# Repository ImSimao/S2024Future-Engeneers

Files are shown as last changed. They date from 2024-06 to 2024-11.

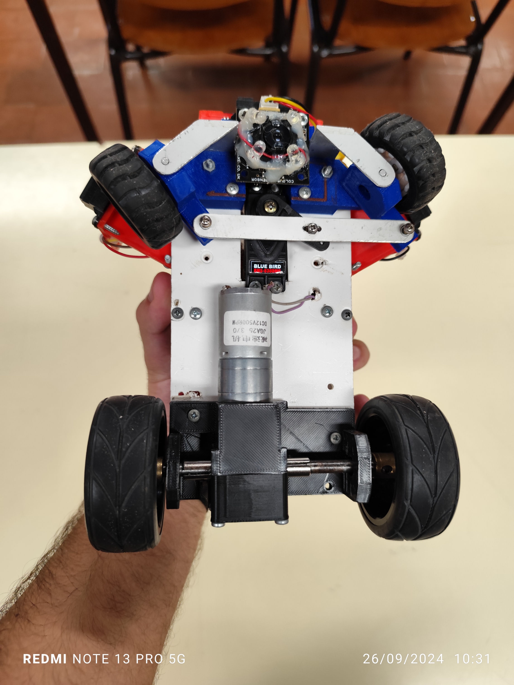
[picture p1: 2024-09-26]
v-photos/Under.jpg

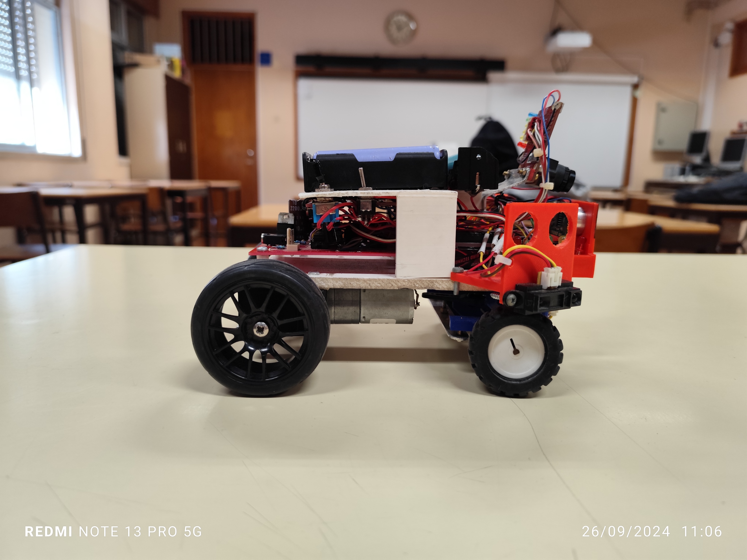
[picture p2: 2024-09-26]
v-photos/Side2.jpg

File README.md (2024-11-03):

# Team and competition

## Presentation of the AGSG Team
We are the AGSG team, we are students and our name is Joana Silva, Simão Freire and Rafael Teodoro, under the guidance of our mentor Tiago Severino. We have the honour to represent Portugal in the World Robot Olympiad competition, in the Future Engineers category.

Official Team

## Competition Challenge
The main challenge in this category is to explore the fundamentals of autonomous driving by building a robot in the shape of a car. This robot must be able to navigate autonomously around a defined track, detecting and dodging obstacles, as well as adapting dynamically to the different conditions imposed during the competition.
Autonomous driving is one of the most significant advances in modern engineering, with applications ranging from personal vehicles to public transport solutions. This challenge not only allows us to demonstrate our skills as a team, but also promotes a space for the exchange of ideas and collaborative learning, contributing to joint evolution in the field of engineering.

## Repository Content
- `other` is for other files which can be used to understand how to prepare the vehicle for the competition. It may include documentation how to connect to a SBC/SBM and upload files there, datasets, hardware specifications, communication protocols descriptions etc. If there is nothing to add to this location, the directory can be removed.
- `schemes` contains one or several schematic diagrams in form of JPEG, PNG or PDF of the electromechanical components illustrating all the elements (electronic components and motors) used in the vehicle and how they connect to each other.
- `src` contains code of control software for all components which were programmed to participate in the competition.
- `t-photos` contains 2 photos of the team (an official one and one funny photo with all team members).
- `v-photos` contains 6 photos of the vehicle (from every side, from top and bottom).
- `video` contains the video.md file with the link to a video where driving demonstration exists.
- `models` is for the files for models used by 3D printers, laser cutting machines and CNC machines to produce the vehicle elements. If there is nothing to add to this location, the directory can be removed.

# Robot Description

## Materials used
The structure of our robot is mostly manufactured using 3D printing or recycled components. For the printed parts, we start with prior planning that includes the shape and dimensions required. We then design the parts using the Tinkercad application and carry out a final visualisation in 3D visualisation software to ensure that the specifications meet our needs before printing. Regarding the parts we reuse, one example is the differential of a toy car, which we adapt to the needs of our robot by giving new life to components that would otherwise be discarded.

Capturar 26 Capturar 25

## Robot Scheme
esquema do robot

## The code: general
We used two software applications to develop our robot. Most of the programming was done in the PICAXE programming editor application, using the PICAXE Basic language. For the camera, we opted for OpenMV, programming in Python.
We have developed three programmes in PICAXE:
      1.	A general programme that controls the robot's movements on the track, reacting when it detects a can, dodges walls, it also reverses or parks.
      2.	A second programme is responsible for reading the blue and orange lines on the track mat, informing the robot in which direction the lap is being taken (clockwise or anti-clockwise) and when to reverse or park.
      3.	A third program that optimises the vehicle's movement, allowing it to move forwards or backwards, saving programming resources and freeing up space in the general programming for other functionalities.
In Python, we programmed the camera to distinguish the colour of green and red obstacles, sending information to the main programming about the direction the robot should go. It also identifies the colour of the car park walls to locate the correct area.

#### The Code: Setup and Compilation
To program, compile and upload the code to the robot we use the picaxe IDE, which is based in basic. When the IDE is running, it asks for the picaxe version, and the cable port. In our robot we use 4 processors, the main processor is a picaxe 28x2, that handles and runs the main code, two processors are slaves, one picaxe 14M2, for the RGB (red, green and blue)  sensor and line counting and the other slave is a picaxe 28x2 for handling the motors. The last processor is integrated in the camera from OpenMV and is programmed in python.
The processors communicate with each other through bits.
The picaxe IDE can be found at https://www.picaxe.com/ it is also needed to install de drivers so it can recognize the cable used for programming, they can also be found at the picaxe website.

#### The Code: Camera
For the camera we use an OpenMV H7 camera and to program it and calibrate it we use the OpenMV IDE. All the libraries required are present in the OpenMV IDE.
In the beginning of the code we initialize the libraries used for the camera The variable screen_division is used to divide the screen in X sections, for example X=3, the screen will be divided and only the bottom 2/3 of the screen will be used to track the obstacles. Then we initialized the variables green_blobs, red_blobs and pink_blobs. The blobs refer to the colour detected by the camera and their position in the screen. Each bracket represents the colour code seen by the camera, there are a few parameters because of the different angles that the camera can see the obstacles.



These thresholds can be obtained from the menu tools/machine vision/Threshold Editor.



Then we adjust the sliders to track just the object that we want to track.



After getting the colour values, we use the blobs position in the screen to send bits to the main processor indicating if the blobs detected are green or red and if they are on the right, left or in the middle.
We also use 1 bit to indicate if it is seeing the parking spot (looking for the pink colour).



Sending the bits to the main processor.



## Mobility Management
Our vehicle is equipped with four wheels, a motor and a differential, which connects the rear wheels. The front wheels are responsible for steering, controlled by a servo that allows the robot to turn left or right as required. The rear wheels connected to the differential was the configuration developed to solve a problem we faced, guaranteeing an even distribution of torque between the half shafts, enabling them to turn in opposite directions and have a different speed range.

Capturar 27

## Energy Management
The robot is powered by four batteries, one of which is a separate power source dedicated specifically to the camera. This approach was implemented to avoid power failures in the camera that would compromise its functionality in distinguishing colours, a challenge we faced during the development of our vehicle.

Capturar 28

## Sensors Management
We chose to use a camera to detect obstacles and the car park, equipping it with a lens that widens the field of view, which solved the difficulties in detecting two consecutive obstacles in a corner. In addition, we incorporated three infrared sensors (Sharp) on the front of the robot: one on each side and one in the centre, capable of measuring the distance to objects by emitting and receiving infrared light. To increase the robot's obstacle detection range, we also added a sonar sensor in the centre of the robot, which measures distances by emitting and receiving sound waves. To identify the colours of the blue and orange lines on the carpet, we used an RGB (red, green and blue) colour sensor, which allows the robot to determine the direction of the race and its position on the laps.

Capturar 31
## Obstacle Management
With regard to obstacle detection, the robot uses the camera with the magnifying lens to identify obstacles, as well as locating the walls of the car park. We have implemented a strategy that allows the robot to bypass obstacles as soon as it detects them, moving to the right if the obstacle is red and to the left if it is green.

# Conclusion
Summarizing, our experience building and programming the robot for the World Robot Olympiad competition not only challenged us to apply theoretical knowledge to a practical project, but also strengthened the spirit of collaboration and innovation within our team. By integrating technologies such as 3D printing, programming in different languages and sensor management, we were able to create a robot capable of navigating autonomously, adapting to different scenarios. We went through several difficulties, some of which are described in this report, and managed to overcome them all, although with a lot of effort, this is a source of great pride.  We are excited to represent Portugal and look forward in applying everything we have learnt when preparing for this competition.

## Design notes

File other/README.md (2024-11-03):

# Other photos taken during the manufactoring process

This board shows photos of the new board we put in the robot when we changed it due to a problem with the previous board and of the soldering of cables that broke and we had to fix. There's also a clear picture of the inside of the robot all together.

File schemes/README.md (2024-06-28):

Electromechanical diagrams
====

The camera schematics can be found at the openmv webiste: https://openmv.io/products/openmv-cam-h7

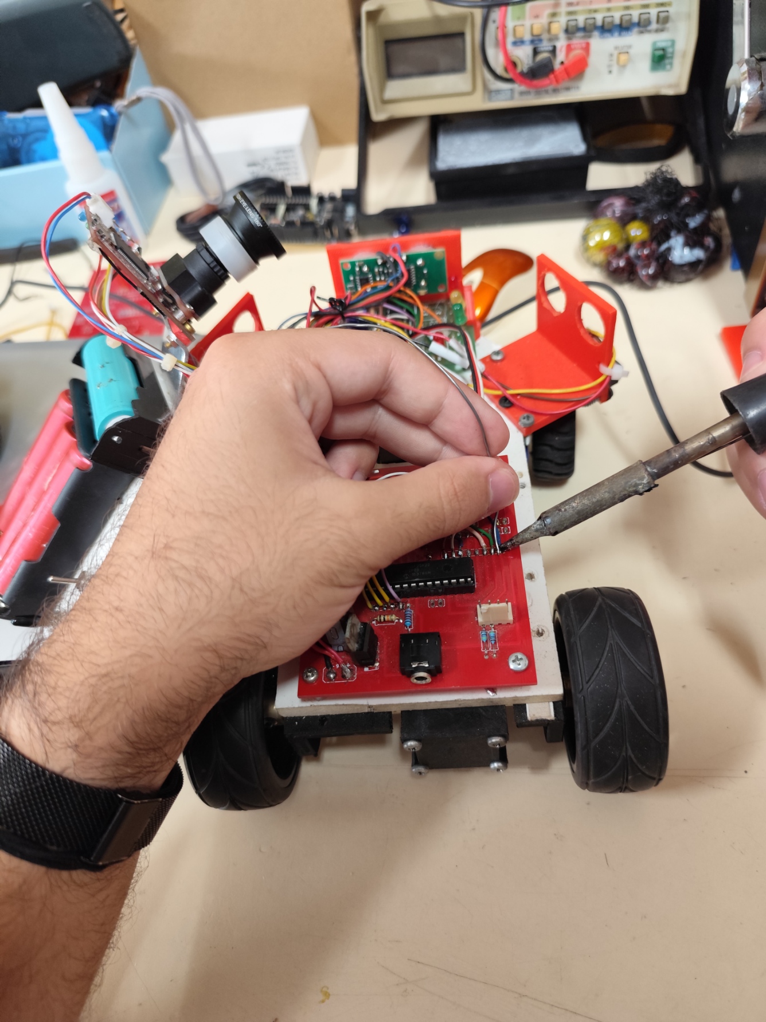
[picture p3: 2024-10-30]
other/broken cable.jpg

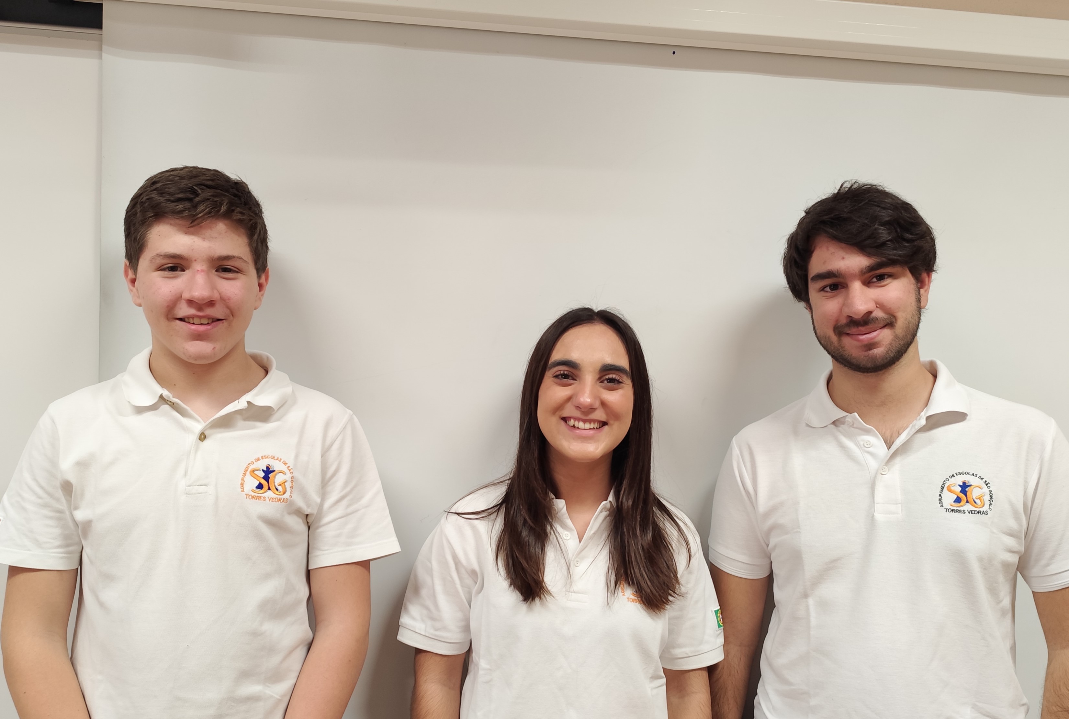
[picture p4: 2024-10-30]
t-photos/Official Team.jpg

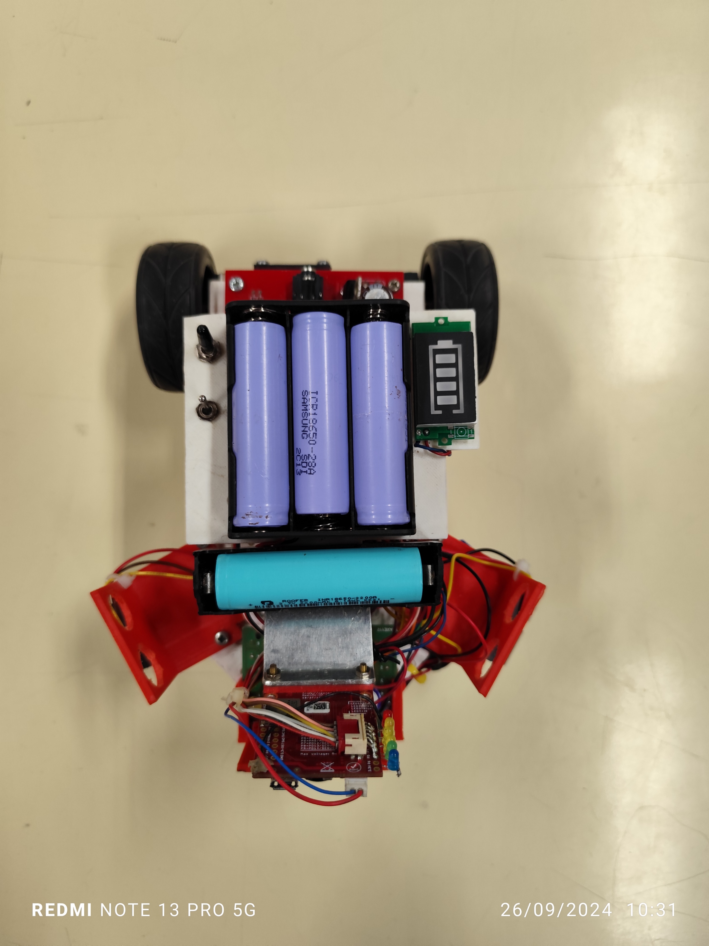
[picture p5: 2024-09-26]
v-photos/Top.jpg

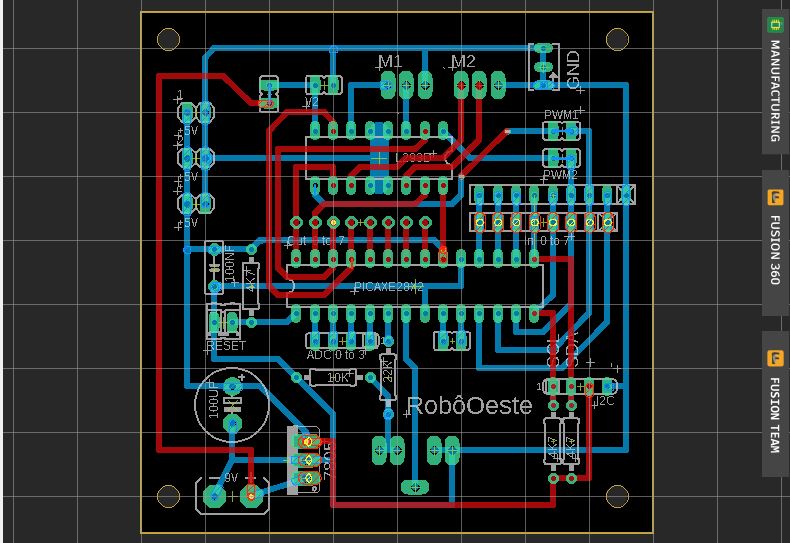
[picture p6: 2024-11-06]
other/pcb.JPG

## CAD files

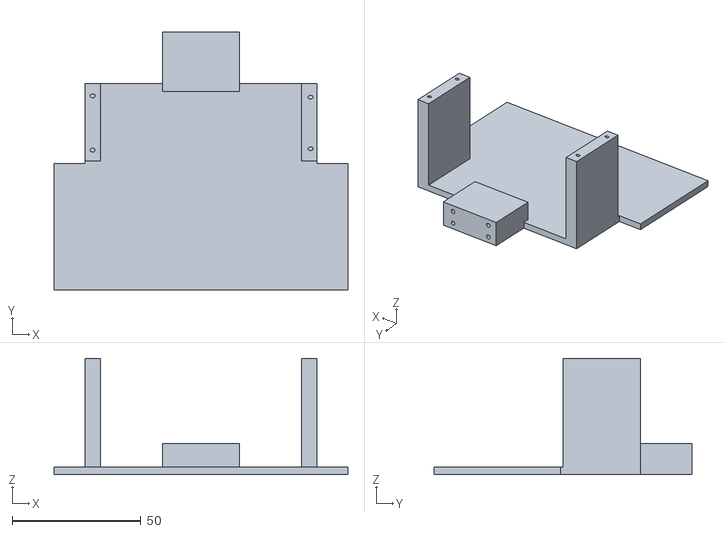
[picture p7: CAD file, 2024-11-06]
models/chassi fut eng..stl
114.0 x 100.0 x 45.0

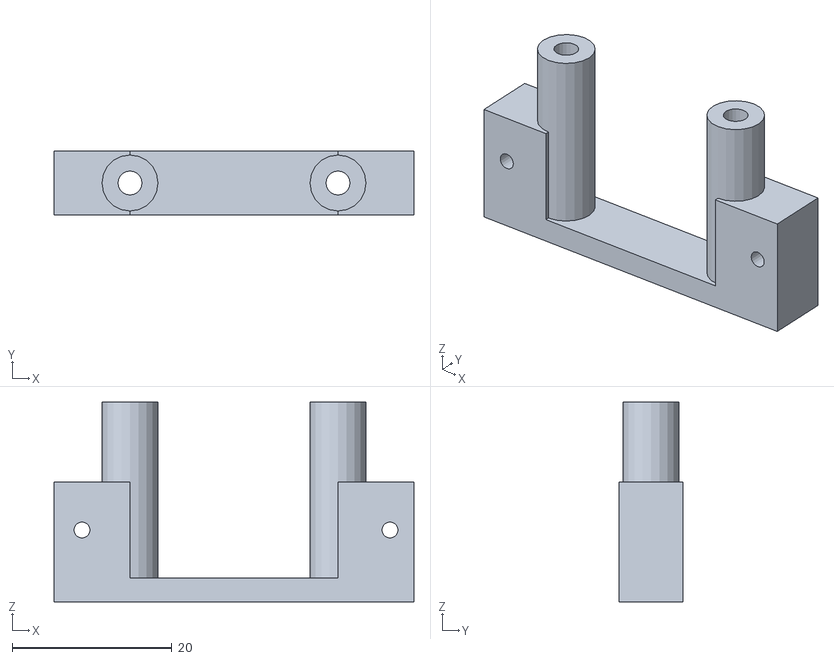
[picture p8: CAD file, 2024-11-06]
models/lower sharp.stl
45.0 x 8.00 x 25.0

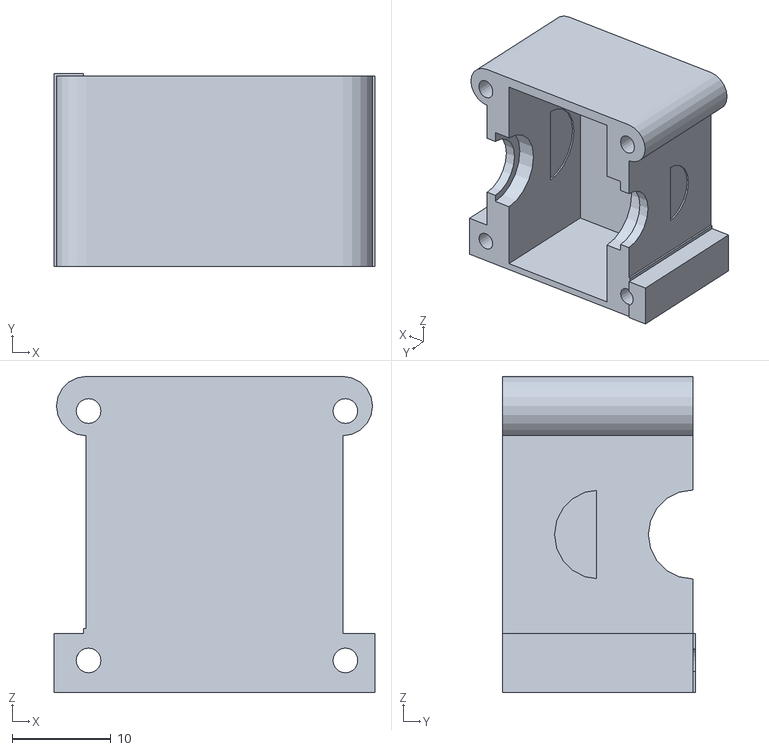
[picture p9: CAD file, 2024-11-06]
models/differential cover.stl
32.5 x 19.5 x 32.0

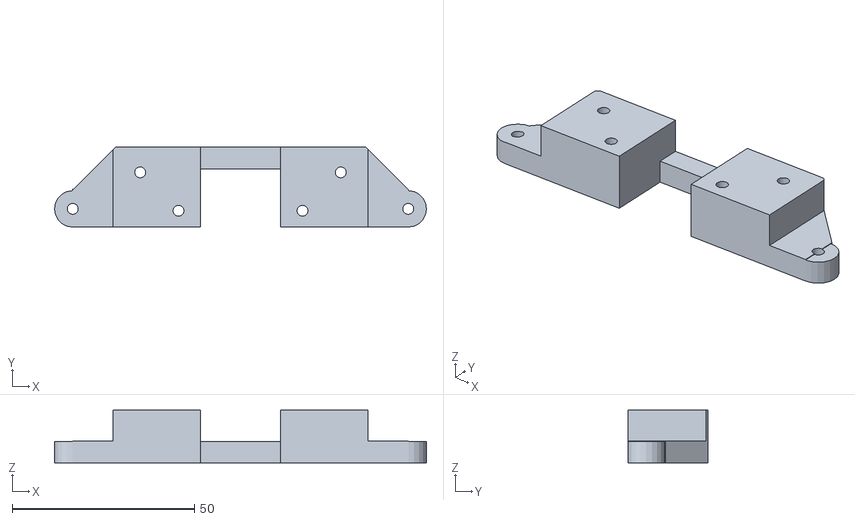
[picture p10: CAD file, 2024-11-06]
models/direction.stl
102.0 x 22.0 x 14.5

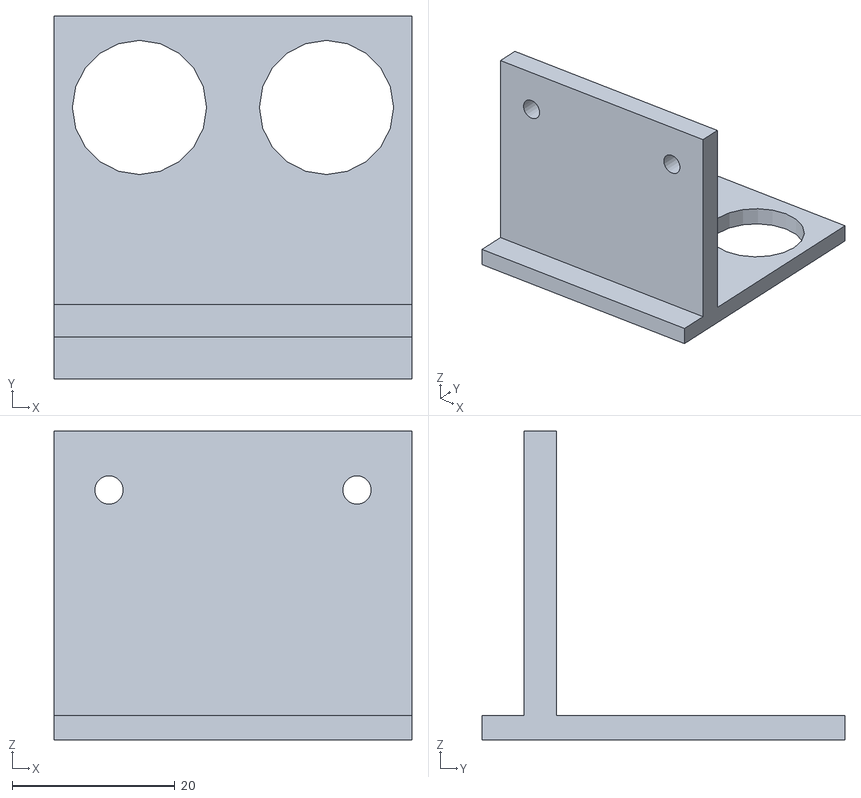
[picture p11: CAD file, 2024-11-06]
models/sonar.stl
44.0 x 44.6 x 38.0

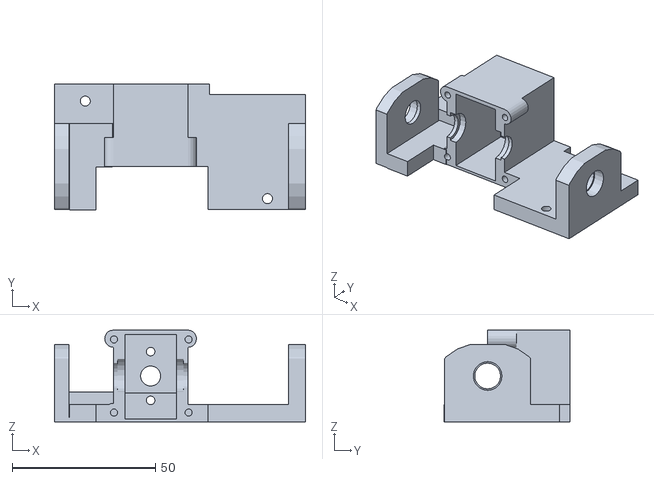
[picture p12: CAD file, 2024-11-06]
models/differential.stl
87.5 x 44.0 x 32.0

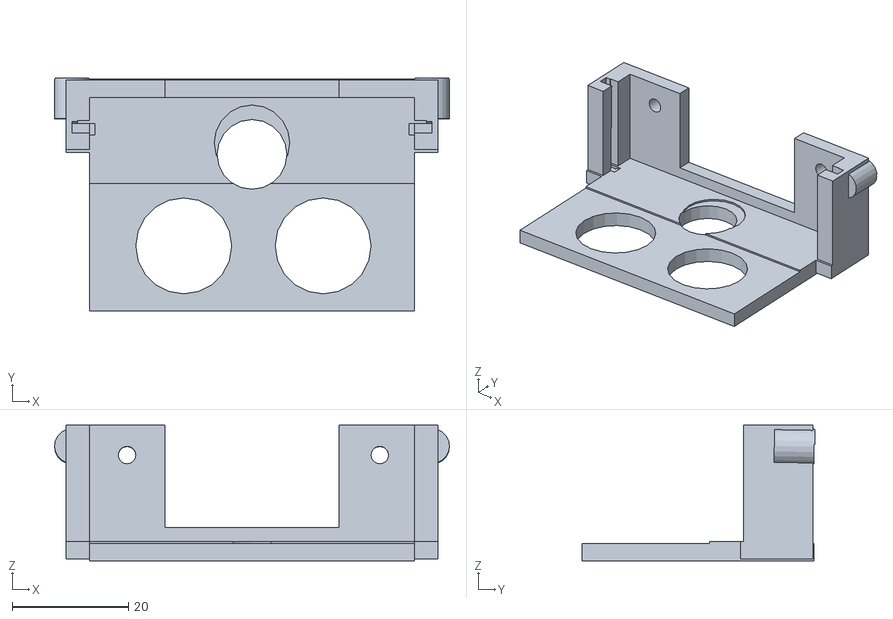
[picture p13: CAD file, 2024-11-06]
models/front sonar.stl
68.0 x 40.2 x 23.4

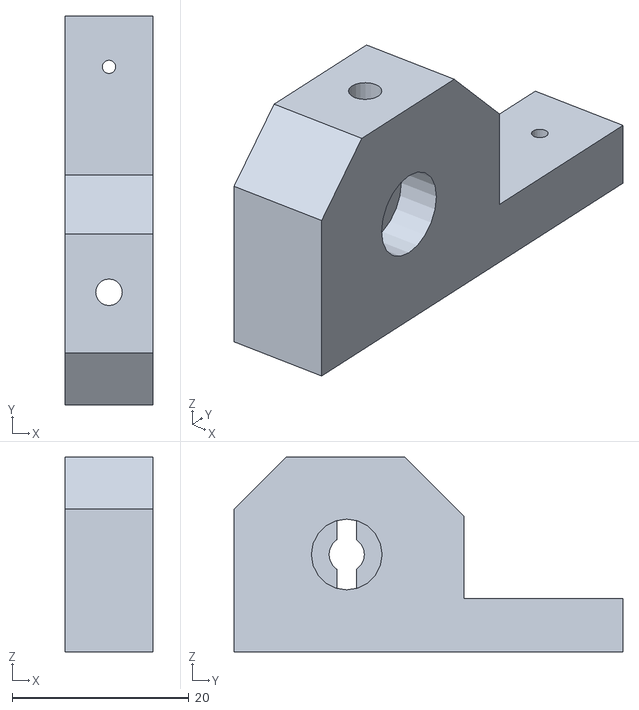
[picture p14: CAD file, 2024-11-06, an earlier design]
models/direction (2).stl
10.0 x 44.0 x 22.0

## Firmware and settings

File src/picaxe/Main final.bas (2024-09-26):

'no sharp a 400 o robot está mais perto do objeto que a 200
'no sonar a 400 o robot está mais longe do objeto que a 200



#no_data
#no_table

b30=22

inicio:
low c.3              'led testes
serout c.5, N2400,(00)
servo 0, 125             '120
pause 100
goto primeira_parte




'###########################################################################################
'###########################################################################################
'###########################################################################################
'###########################################################################################
'###########################################################################################
'###########################################################################################




primeira_parte:

if pinb.3=0 and pinb.2=0 then frente_primeira_vez           'PERGUNTA AO SENSOR RGB  b.3 azul    -    b.2 laranja 
if pinb.3=1 and pinb.2=0 then informa_rgb_ar                'AZUL
if pinb.3=0 and pinb.2=1 then informa_rgb_r                 'LARANJA



informa_rgb_ar:
high c.2                        'envia informação do inverter a marcha para a placa do RGB
gosub parado_return
pause 200
low c.2
goto anti_relogio



informa_rgb_r:
low c.2                         'envia informação do inverter a marcha para a placa do RGB
gosub parado_return
pause 200
low c.2
goto relogio



frente_primeira_vez:
if pinb.4=0 and pinb.5=0 and pinb.6=0  then seguir_parede
if pinb.4=0 and pinb.5=1 and pinb.6=0  then cores  
if pinb.4=0 and pinb.5=0 and pinb.6=1  then cores
if pinb.4=1 and pinb.5=0 and pinb.6=0  then cores



seguir_parede:


readadc10 0, w4  'esquerda
readadc10 1, w5  'frente
readadc10 2, w6  'direita


if w4<420 and w5<100 and w6<420 then frente
if w4>420 and w5<100 and w6>420 then frente
if w4>420 and w5>100 and w6>420 then frente
if w4>420 and w5<100 and w6<420 then direita
if w4<420 and w5>100 and w6<420 then frente
if w4<420 and w5<100 and w6>420 then esquerda
if w4>420 and w5>100 and w6<420 then direita
if w4<420 and w5>100 and w6>420 then esquerda



'###########################################################################################
'###########################################################################################
'###########################################################################################
'###########################################################################################
'###########################################################################################


frente:
serout c.5, N2400,(b30)
servo 0, 125                 '125 no centro
pause 1
goto primeira_parte



direita:
readadc10 1, w5  'frente

if w5<350 then direita_desvio
if w5>349 then recua_especial_dir


recua_especial_dir:
high c.1                    
serout c.5, N2400,(22)   
servo 0,125                '125 no centro
pause 800          
low c.1

serout c.5, N2400,(22)
servo 0, 170
pause 300
goto primeira_parte    'ciclo do contornar verde



direita_desvio:
serout c.5, N2400,(b30)
servo 0,155      
pause 1
goto primeira_parte



esquerda:
readadc10 1, w5  'frente

if w5<350 then esquerda_desvio
if w5>349 then recua_especial_esq


recua_especial_esq:
high c.1                    
serout c.5, N2400,(22)   
servo 0,125                '125 no centro
pause 800          
low c.1

serout c.5, N2400,(22)
servo 0, 80
pause 300
goto primeira_parte    'ciclo do contornar verde



esquerda_desvio:
serout c.5, N2400,(b30)
servo 0, 95
pause 1
goto primeira_parte



'###########################################################################################
'###########################################################################################
'###########################################################################################
'###########################################################################################
'###########################################################################################


cores:
if pinb.7=1 and pinc.6=1 then seguir_parede
if pinb.7=0 and pinc.6=1 then contornar_verde
if pinb.7=1 and pinc.6=0 then contornar_vermelho
if pinb.7=0 and pinc.6=0 then seguir_parede


'###########################################################################################
'###########################################################################################
'###########################################################################################


contornar_verde:
if pinb.3=0 and pinb.2=0 then segue_cortornar_verde           'PERGUNTA AO SENSOR RGB  b.3 azul    -    b.2 laranja 
if pinb.3=1 and pinb.2=0 then informa_rgb_ar                'AZUL
if pinb.3=0 and pinb.2=1 then informa_rgb_r                 'LARANJA


  
segue_cortornar_verde:
if pinb.4=0 and pinb.5=0 and pinb.6=0  then verificar_verde
if pinb.4=0 and pinb.5=1 and pinb.6=0  then deviar_verde    
if pinb.4=0 and pinb.5=0 and pinb.6=1  then deviar_verde
if pinb.4=1 and pinb.5=0 and pinb.6=0  then deviar_verde



deviar_verde:
PULSOUT c.0, 1     
PULSIN c.0, 1, w1          'sonar da frente

if w1<250 then recua_temporizada_verde 
if w1>249 then deviar_verde_3


deviar_verde_3:
serout c.5, N2400,(b30)
servo 0, 80               'vira para esquerda
pause 1
goto contornar_verde    'ciclo do contornar verde


recua_temporizada_verde:
high c.1                    
serout c.5, N2400,(22)   
servo 0,125                '125 no centro
pause 900          
low c.1
goto contornar_verde    'ciclo do contornar verde



verificar_verde:
for b0=1 to 70
gosub verificar_verde_3
next b0
goto frente       'vai para o inicio


verificar_verde_3:
if pinb.3=0 and pinb.2=0 then segue_verificar_verde           'PERGUNTA AO SENSOR RGB  b.3 azul    -    b.2 laranja 
if pinb.3=1 and pinb.2=0 then informa_rgb_ar                'AZUL
if pinb.3=0 and pinb.2=1 then informa_rgb_r                 'LARANJA



segue_verificar_verde:
if pinb.4=0 and pinb.5=0 and pinb.6=0  then frente_pos_verde
if pinb.4=0 and pinb.5=1 and pinb.6=0  then cores
if pinb.4=0 and pinb.5=0 and pinb.6=1  then cores    
if pinb.4=1 and pinb.5=0 and pinb.6=0  then cores 




'###########################################################################################
'###########################################################################################
'###########################################################################################



contornar_vermelho:
if pinb.3=0 and pinb.2=0 then segue_cortornar_vermelho           'PERGUNTA AO SENSOR RGB  b.3 azul    -    b.2 laranja 
if pinb.3=1 and pinb.2=0 then informa_rgb_ar                'AZUL
if pinb.3=0 and pinb.2=1 then informa_rgb_r 



segue_cortornar_vermelho:
if pinb.4=0 and pinb.5=0 and pinb.6=0  then verificar_vermelho
if pinb.4=0 and pinb.5=1 and pinb.6=0  then desviar_vermelho
if pinb.4=0 and pinb.5=0 and pinb.6=1  then desviar_vermelho     
if pinb.4=1 and pinb.5=0 and pinb.6=0  then desviar_vermelho



desviar_vermelho:
PULSOUT c.0, 1     
PULSIN c.0, 1, w1                  'sonar da frente

if w1<250 then recua_temporizada_vermelho
if w1>249 then desviar_vermelho_3



desviar_vermelho_3:
readadc10 0, w6         'SHARP esquerda                          'testar
if w6<250 then desviar_vermelho_3_2
if w6>250 then frente


desviar_vermelho_3_2:
serout c.5, N2400,(b30)
servo 0, 150               'vira para esquerda
pause 1
goto contornar_vermelho    'ciclo do contornar vermelho


recua_temporizada_vermelho:
high c.1                    
serout c.5, N2400,(22)   
servo 0,125                      '125 no centro
pause 900
low c.1
goto contornar_vermelho    'ciclo do contornar vermelho



verificar_vermelho:
for b0=1 to 82     
gosub verificar_vermelho_3
next b0
goto frente      'vai para o inicio


verificar_vermelho_3:
if pinb.3=0 and pinb.2=0 then segue_verificar_vermelho           'PERGUNTA AO SENSOR RGB  b.3 azul    -    b.2 laranja 
if pinb.3=1 and pinb.2=0 then informa_rgb_ar                'AZUL
if pinb.3=0 and pinb.2=1 then informa_rgb_r                 'LARANJA


segue_verificar_vermelho:
if pinb.4=0 and pinb.5=0 and pinb.6=0  then frente_pos_vermelho
if pinb.4=0 and pinb.5=1 and pinb.6=0  then cores
if pinb.4=0 and pinb.5=0 and pinb.6=1  then cores     
if pinb.4=1 and pinb.5=0 and pinb.6=0  then cores 



'###########################################################################################
'###########################################################################################
'###########################################################################################
'###########################################################################################
'###########################################################################################
'###########################################################################################
'###########################################################################################
'###########################################################################################
'###########################################################################################




relogio:                               'direita
if pina.3=0 then seguir_r
if pina.3=1 then estacionamento_r



seguir_r:
if pinb.1=1 then pergunta_flag_r       'pergunta led amarelo - se tem 2 voltas está ligado
if pinb.1=0 then continuar_relogio



pergunta_flag_r:
if b1=1 then inverter_marcha_r         'pergunta a FLAG b1                      c,3 é a flag
if b1=0 then continuar_relogio



continuar_relogio:
if pinb.4=0 and pinb.5=0 and pinb.6=0  then seguir_parede_r
if pinb.4=0 and pinb.5=1 and pinb.6=0  then cores_r
if pinb.4=0 and pinb.5=0 and pinb.6=1  then cores_r
if pinb.4=1 and pinb.5=0 and pinb.6=0  then cores_r


seguir_parede_r:
readadc10 0, w4  'esquerda
readadc10 1, w5  'frente
readadc10 2, w6  'direita



if w4<80 and w5<100 and w6<120 then frente_r
if w4>80 and w5<100 and w6>120 then frente_r
if w4>80 and w5>100 and w6>120 then frente_r
if w4>80 and w5<100 and w6<120 then direita_r
if w4<80 and w5>100 and w6<120 then confirmar_canto_r                'direita_canto_r
if w4<80 and w5<100 and w6>120 then esquerda_r
if w4>80 and w5>100 and w6<120 then direita_r
if w4<80 and w5>100 and w6>120 then esquerda_r



'###########################################################################################
'###########################################################################################
'###########################################################################################



frente_r:
serout c.5, N2400,(b30)
servo 0, 125                 '125 no centro
pause 1
goto relogio


direita_r:
readadc10 1, w5  'frente

if w5<350 then direita_desvio_r
if w5>349 then recua_especial_dir_r


recua_especial_dir_r:
high c.1                    
serout c.5, N2400,(22)   
servo 0,125                '125 no centro
pause 800          
low c.1

serout c.5, N2400,(22)
servo 0, 170
pause 300
goto relogio    'ciclo do contornar verde



direita_desvio_r:
serout c.5, N2400,(b30)
servo 0,155      
pause 1
goto relogio


esquerda_r:
readadc10 1, w5  'frente

if w5<350 then esquerda_desvio_r
if w5>349 then recua_especial_esq_r


recua_especial_esq_r:
high c.1                    
serout c.5, N2400,(22)   
servo 0,125                '125 no centro
pause 800          
low c.1

serout c.5, N2400,(22)
servo 0, 80
pause 300
goto relogio    'ciclo do contornar verde



esquerda_desvio_r:
serout c.5, N2400,(b30)
servo 0, 95
pause 1
goto relogio



confirmar_canto_r:
readadc10 2, w6        'SHARP direita

if w6<100 then direita_canto_r
if w6>100 then frente_r


direita_canto_r:
serout c.5, N2400,(25)            
servo 0,170           
pause 600
goto relogio

'###########################################################################################
'###########################################################################################
'###########################################################################################
'###########################################################################################
'###########################################################################################


cores_r:

if pinb.7=1 and pinc.6=1 then relogio
if pinb.7=0 and pinc.6=1 then contornar_verde_r
if pinb.7=1 and pinc.6=0 then contornar_vermelho_r
if pinb.7=0 and pinc.6=0 then relogio



'###########################################################################################
'###########################################################################################
'###########################################################################################



contornar_verde_r: 
let b1=0                    'carregar a flag   

if pinb.4=0 and pinb.5=0 and pinb.6=0  then verificar_verde_r
if pinb.4=0 and pinb.5=1 and pinb.6=0  then deviar_verde_r     
if pinb.4=0 and pinb.5=0 and pinb.6=1  then deviar_verde_r
if pinb.4=1 and pinb.5=0 and pinb.6=0  then deviar_verde_r



deviar_verde_r:
PULSOUT c.0, 1     
PULSIN c.0, 1, w1          'sonar da frente

if w1<250 then recua_temporizada_verde_r 
if w1>249 then deviar_verde_3_r


deviar_verde_3_r:
serout c.5, N2400,(b30)
servo 0, 80               'vira para esquerda
pause 1
goto contornar_verde_r    'ciclo do contornar verde


recua_temporizada_verde_r:
high c.1                    
serout c.5, N2400,(22)   
servo 0,125                '125 no centro
pause 600          
low c.1
goto contornar_verde_r    'ciclo do contornar verde



verificar_verde_r:
for b0=1 to 100
gosub verificar_verde_3_r
next b0
goto frente_r       'vai para o inicio


verificar_verde_3_r:
if pinb.4=0 and pinb.5=0 and pinb.6=0  then frente_pos_verde_r
if pinb.4=0 and pinb.5=1 and pinb.6=0  then cores_r
if pinb.4=0 and pinb.5=0 and pinb.6=1  then cores_r     
if pinb.4=1 and pinb.5=0 and pinb.6=0  then cores_r 



'###########################################################################################
'###########################################################################################
'###########################################################################################




contornar_vermelho_r:
let b1=1                     'carregar a flag

if pinb.4=0 and pinb.5=0 and pinb.6=0  then verificar_vermelho_r
if pinb.4=0 and pinb.5=1 and pinb.6=0  then desviar_vermelho_r
if pinb.4=0 and pinb.5=0 and pinb.6=1  then desviar_vermelho_r     
if pinb.4=1 and pinb.5=0 and pinb.6=0  then desviar_vermelho_r



desviar_vermelho_r:
PULSOUT c.0, 1     
PULSIN c.0, 1, w1                  'sonar da frente

if w1<250 then recua_temporizada_vermelho_r 
if w1>249 then desviar_vermelho_3_r



desviar_vermelho_3_r:
readadc10 2, w6         'SHARP direita                          'testar
if w6<300 then desviar_vermelho_3_r2
if w6>300 then desvia_da_parede_r



desviar_vermelho_3_r2:
serout c.5, N2400,(b30)
servo 0, 150               'vira para esquerda
pause 1
goto contornar_vermelho_r    'ciclo do contornar vermelho



desvia_da_parede_r:
serout c.5, N2400,(b30)
servo 0,125                 'andar em frente
pause 1
goto  contornar_vermelho_r    'ciclo do contornar vermelho



recua_temporizada_vermelho_r:
high c.1                    
serout c.5, N2400,(22)   
servo 0,125                      '125 no centro
pause 600
low c.1
goto contornar_vermelho_r  'ciclo do contornar vermelho



verificar_vermelho_r:
for b0=1 to 100     
gosub verificar_vermelho_3_r
next b0
goto frente_r    'vai para o inicio


verificar_vermelho_3_r:
if pinb.4=0 and pinb.5=0 and pinb.6=0  then frente_pos_vermelho_r
if pinb.4=0 and pinb.5=1 and pinb.6=0  then cores_r
if pinb.4=0 and pinb.5=0 and pinb.6=1  then cores_r     
if pinb.4=1 and pinb.5=0 and pinb.6=0  then cores_r 




'###########################################################################################
'###########################################################################################
'###########################################################################################
'###########################################################################################
'###########################################################################################


inverter_marcha_r:

high c.2                     'informa inverter a marcha para a placa do RGB 

gosub parado_return
pause 100

gosub frente_return_r
pause 1400

gosub recua_inverter_r

gosub frentecontrol_inverter_r


recua_inverter_r:
high c.1
serout c.5, N2400,(25)
servo 0, 175
pause 1700             'esquerda6
low c.1
return


frentecontrol_inverter_r:
PULSOUT c.0, 1     
PULSIN c.0, 1, w1          'sonar da frente

if w1<250 then recua_torto_inverter_r
if w1>250 then frente_inverter_r



frente_inverter_r:
serout c.5, N2400,(25)
servo 0, 125 
pause 1            'esquerda6
goto frentecontrol_inverter_r


recua_torto_inverter_r:
high c.1
serout c.5, N2400,(25)
servo 0, 175
pause 1400             'esquerda6
low c.1
goto anti_relogio




'###########################################################################################
'###########################################################################################
'###########################################################################################
'###########################################################################################
'###########################################################################################



estacionamento_r:
high c.1                    
serout c.5, N2400,(25)   
servo 0,125                    'recuar
pause 700
low c.1

serout c.5, N2400,(25)         'direita 
servo 0,70      
pause 1300
goto procura_parede_r



procura_parede_r:
for b0=1 to 256      
gosub frente_parede_r
next b0


frente_parede_r:
PULSOUT c.0, 1     
PULSIN c.0, 1, w1                  'sonar da frente

if w1<200 then recua_estacionamento_r 
if w1>200 then frente_ate_parede_r 



frente_ate_parede_r:
serout c.5, N2400,(25)
servo 0,125      
pause 1
goto frente_parede_r



recua_estacionamento_r:              'recuar torto
high c.1                    
serout c.5, N2400,(21)   
servo 0,70
pause 1400          
low c.1
goto frente_contorlado_r    



frente_contorlado_r:
PULSOUT c.0, 1     
PULSIN c.0, 1, w1                  'sonar da frente

if w1<500 then seguir_direita_r
if w1>500 then frente_reto_r 



frente_reto_r:
serout c.5, N2400,(25)
servo 0,125      
pause 1
goto frente_contorlado_r



seguir_direita_r:                'para ficar paralelo à parede
serout c.5, N2400,(25)
servo 0, 155
pause 1500
goto seguir_estacionamento_r



seguir_estacionamento_r:
if pinb.2=0 then seguir_estacionamento_r2           'PERGUNTA AO SENSOR RGB  b.3 azul    -    b.2 laranja 
if pinb.2=1 then canto_laranja_r                'AZUL


canto_laranja_r:
serout c.5, N2400,(25)
servo 0, 150                 '125 no centro
pause 700
goto frente_laranja_r


frente_laranja_r:
PULSOUT c.0, 1     
PULSIN c.0, 1, w1                  'sonar da frente

if w1<350 then virar_laranja_r
if w1>350 then frente_reto_laranja_r 


virar_laranja_r:
serout c.5, N2400,(25)
servo 0, 155                 '125 no centro
pause 1000
goto seguir_estacionamento_r



frente_reto_laranja_r:
serout c.5, N2400,(25)
servo 0,125      
pause 1
goto frente_laranja_r



seguir_estacionamento_r2:

if pinc.7=0 then seguir_estacionamento_ver_r
if pinc.7=1 then estacionar_final_r




seguir_estacionamento_ver_r:
readadc10 0, w4         'SHARP esquerda
pause 1

if w4<450 then esquerda_ligeiro_r 
if w4>450 and w4<550 then frente_ligeiro_r
if w4>550 then direita_ligeiro_r



direita_ligeiro_r:
serout c.5, N2400,(b30)
servo 0,155      
pause 1
goto seguir_estacionamento_r



frente_ligeiro_r:
serout c.5, N2400,(b30)
servo 0,125      
pause 1
goto seguir_estacionamento_r



esquerda_ligeiro_r:
serout c.5, N2400,(b30)
servo 0,95      
pause 1
goto seguir_estacionamento_r



estacionar_final_r:
readadc10 1, w5  'frente

if w5<450 then frente_ate_rosa_r
if w5>450 then entrar_estacionamento_r



frente_ate_rosa_r:
readadc10 0, w4         'SHARP esquerda
pause 1

if w4<450 then esquerda_final_r 
if w4>450 and w4<550 then frente_final_r
if w4>550 then direita_final_r



direita_final_r:
serout c.5, N2400,(b30)
servo 0,155      
pause 1
goto estacionar_final_r



frente_final_r:
serout c.5, N2400,(b30)
servo 0,125      
pause 1
goto estacionar_final_r



esquerda_final_r:
serout c.5, N2400,(b30)
servo 0,95      
pause 1
goto estacionar_final_r




entrar_estacionamento_r:
high c.1                    
serout c.5, N2400,(25)   
servo 0,80
pause 800          
low c.1

serout c.5, N2400,(25)
servo 0,170      
pause 600

serout c.5, N2400,(25)
servo 0,80      
pause 2900

serout c.5, N2400,(25)
servo 0,125      
pause 100

goto parar_ar



'###########################################################################################
'###########################################################################################
'###########################################################################################
'###########################################################################################
'###########################################################################################
'###########################################################################################
'###########################################################################################
'###########################################################################################
'###########################################################################################





anti_relogio: 'esquerda
if pina.3=0 then seguir_ar
if pina.3=1 then estacionamento_ar



seguir_ar:
if pinb.1=1 then pergunta_flag_ar       'pergunta led amarelo - se tem 2 voltas está ligado
if pinb.1=0 then continuar_anti_relogio



pergunta_flag_ar:
if b1=1 then inverter_marcha_ar         'pergunta a FLAG b1         c,3 é a flag
if b1=0 then continuar_anti_relogio
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

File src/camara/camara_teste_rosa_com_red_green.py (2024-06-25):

import math

import pyb
import sensor

debug = True
min_width = 18
min_height = 35
screen_division = 3

# Color Tracking Thresholds (L Min, L Max, A Min, A Max, B Min, B Max)
green_blobs = [
    #(20, 39, -27, -3, -12, 15),
    #(24, 45, -19, -9, -9, 11),
    #(17, 43, -42, -6, -9, 18),
    #(28, 73, -65, -13, -34, 21),
    #(19, 53, -34, -6, -2, 17)
        #(45, 60, -57, -37, 6, 43),
        #(35, 59, -55, -16, -9, 40),
        #(44, 58, -54, -26, 5, 45),
        #(35, 61, -59, -32, 7, 38),
        #(29, 53, -38, -13, -8, 15)
            (39, 61, -48, -21, -9, 22),
            (36, 68, -52, -12, -15, 30),    #verde perto / pode estar mt aberto
            (25, 43, -40, -9, 0, 18),
            (32, 53, -54, -18, 0, 25)

]


pink_blobs = [

   (23, 44, 23, 57, -15, 2),
   (24, 43, 28, 58, -6, 7),
   (31, 69, 51, 72, -56, -30)



]


red_blobs = [
    #(6, 30, 11, 43, -12, 44),
    #(9, 37, 20, 64, 12, 43),
    #(15, 57, 22, 63, -11, 32)
        #(14, 30, 18, 58, -2, 53),
        #(19, 36, 28, 57, -1, 45),
        #(31, 59, 45, 76, -46, 48),
        #(15, 32, 13, 52, -2, 22)
            #(13, 27, 13, 44, 3, 23),        #valores que estam na camara mas com falta de afinação
            #(17, 35, 17, 56, -2, 39),
            #(15, 35, 24, 56, -3, 28),
            #(13, 40, 28, 75, -23, 54)
               # (20, 31, 13, 55, 3, 39),
               # (22, 39, 21, 55, -21, 21),
               # (21, 33, 25, 55, -2, 25),
               # (18, 36, 19, 58, -4, 29)
                    #(22, 39, 41, 64, 12, 51),
                    #(28, 40, 47, 64, 20, 55),
                    #(34, 42, 57, 67, 34, 53),
                    #(32, 40, 53, 63, 35, 57),
                    #(23, 37, 25, 52, -5, 32)
                        #(16, 35, 12, 56, -3, 18),
                        #(17, 37, 13, 64, -4, 30),
                        #(12, 32, 14, 53, -3, 23),
                        #(14, 40, 20, 56, -13, 17),
                        #(31, 53, 43, 61, 8, 35),
                        #(29, 39, 48, 57, 23, 46)
                            #09/05/2024
                            (21, 49, 45, 65, 7, 38),
                            (15, 31, 18, 51, 8, 28),
                            (29, 44, 49, 59, 4, 34),
                            (10, 32, 18, 42, 7, 24),
                            (26, 36, 39, 54, 13, 29),
                            (15, 37, 33, 51, 12, 37)
                                #(24, 37, 36, 60, 11, 24),
                                #(17, 42, 38, 56, 13, 41),
                                #(20, 26, 27, 45, 10, 33),
                                #(15, 32, 29, 55, 14, 35)



 ]

sensor.reset()
sensor.set_pixformat(sensor.RGB565)
sensor.set_framesize(sensor.QVGA)
sensor.skip_frames(time=2000)
sensor.set_auto_gain(False) # must be turned off for color tracking
sensor.set_auto_whitebal(False) # must be turned off for color tracking
sensor.set_vflip(True)
sensor.set_hmirror(True)


p0 = pyb.Pin("P0", pyb.Pin.OUT_PP)
p1 = pyb.Pin("P1", pyb.Pin.OUT_PP)
p2 = pyb.Pin("P2", pyb.Pin.OUT_PP)
p3 = pyb.Pin("P3", pyb.Pin.OUT_PP)
p4 = pyb.Pin("P4", pyb.Pin.OUT_PP)
p5 = pyb.Pin("P5", pyb.Pin.OUT_PP)

# Only blobs that with more pixels than "pixel_threshold" and more area than "area_threshold" are
# returned by "find_blobs" below. Change "pixels_threshold" and "area_threshold" if you change the
# camera resolution. Don't set "merge=True" becuase that will merge blobs which we don't want here.

while(True):
    img = sensor.snapshot()
    blob_detected = False
    largest_blob = False
    is_red_blob = False
    is_green_blob = False
    is_pink_blob = False

    try:
        for blob in img.find_blobs(green_blobs, pixels_threshold=500, area_threshold=500, merge=False):
            if (blob.cy() < img.height()/screen_division):
                continue

            if (blob.h() < min_height or blob.w() < min_width):
                continue

            # These values depend on the blob not being circular - otherwise they will be shaky.
            if largest_blob is False or blob.cy() > largest_blob.cy():
                largest_blob = blob
                is_green_blob = True

            blob_detected=True

            if not debug:
                continue

            img.draw_edges(blob.min_corners(), color=(255,0,0))
            img.draw_line(blob.major_axis_line(), color=(0,255,0))
            img.draw_line(blob.minor_axis_line(), color=(0,0,255))
            # These values are stable all the time.
            img.draw_rectangle(blob.rect(), color=(0,255,0))
            img.draw_cross(blob.cx(), blob.cy())
            # Note - the blob rotation is unique to 0-180 only.
            img.draw_keypoints([(blob.cx(), blob.cy(), int(math.degrees(blob.rotation())))], size=20)

        for blob in img.find_blobs(red_blobs, pixels_threshold=500, area_threshold=500, merge=False):
            if (blob.cy() < img.height()/screen_division):
                continue

            if (blob.h() < min_height or blob.w() < min_width):
                continue

            # These values depend on the blob not being circular - otherwise they will be shaky.
            if largest_blob is False or blob.cy() > largest_blob.cy():
                largest_blob = blob
                is_red_blob = True


            blob_detected=True

            if not debug:
                continue

            img.draw_edges(blob.min_corners(), color=(255,0,0))
            img.draw_line(blob.major_axis_line(), color=(0,255,0))
            img.draw_line(blob.minor_axis_line(), color=(0,0,255))
            # These values are stable all the time.
            img.draw_rectangle(blob.rect(), color=(255,0,0))
            img.draw_cross(blob.cx(), blob.cy())

            # Note - the blob rotation is unique to 0-180 only.
            img.draw_keypoints([(blob.cx(), blob.cy(), int(math.degrees(blob.rotation())))], size=20)

        for blob in img.find_blobs(pink_blobs, pixels_threshold=500, area_threshold=500, merge=False):


            # These values depend on the blob not being circular - otherwise they will be shaky.
            if largest_blob is False or blob.cy() > largest_blob.cy():
            #    largest_blob = blob
                is_pink_blob = True


            blob_detected=True

            if not debug:
                continue

            img.draw_edges(blob.min_corners(), color=(255,0,0))
            img.draw_line(blob.major_axis_line(), color=(0,255,0))
            img.draw_line(blob.minor_axis_line(), color=(0,0,255))
            # These values are stable all the time.
            img.draw_rectangle(blob.rect(),color=(0,0,0))
            img.draw_cross(blob.cx(), blob.cy())
            # Note - the blob rotation is unique to 0-180 only.
            img.draw_keypoints([(blob.cx(), blob.cy(), int(math.degrees(blob.rotation())))], size=20)

        if blob_detected is False:
            p0.low()
            p1.low()
            p2.low()
            p3.low()
            p4.low()
            p5.low()
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
